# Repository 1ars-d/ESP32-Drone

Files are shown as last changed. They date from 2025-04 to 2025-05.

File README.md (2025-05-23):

# ESP32 Custom Drone

## 🚁 Overview

A compact, custom-built **5.5″ quadcopter drone** powered by an **ESP32 microcontroller**. This project includes both hardware design (3D-printed components, PCB layout) and firmware (Arduino-based) for flight control.

Drone with battery

---

## 🔧 Firmware

The flight control software is written in **C++** using the **Arduino framework**. It runs a **250Hz control loop** to maintain drone stability using the following key features:

- **Sensor Fusion**: A **Kalman Filter** fuses gyroscope and accelerometer data to estimate orientation.
- **Control System**: Stabilization is achieved using a **cascaded PID control loop**.
- **Remote Input**: Directional control is handled via a **radio receiver**.
- **Live PID Tuning**: The drone can host a **local Wi-Fi web interface** for real-time PID tuning.
  > _The web-based tuning interface was adapted from [pratikPhadte/ESP32-Flight-controller-](https://github.com/pratikPhadte/ESP32-Flight-controller-)._

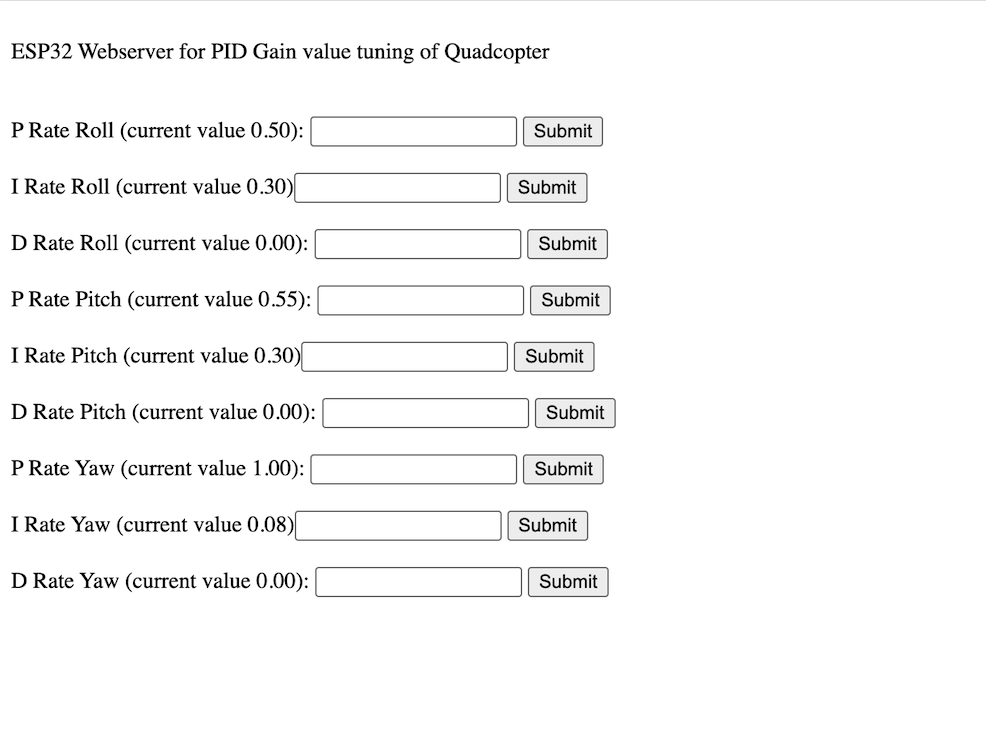
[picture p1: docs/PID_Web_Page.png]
PID Web Page


---

## 🛠️ Hardware Components

| Component | Description | Price |
| --- | --- | --- |
| **Frame** | FlyFishRC FIFTY5 | €50.00  |
| **Radio Receiver** | Flysky FS-IA6B | €20.00  |
| **Flight Controller** | ESP32-DevKitC, MP1584 (Buck Converter), MPU6050 (IMU), PCB | €20.00  |
| **Motors** | 4x FlyfishRC Flash 2306 1750Kv | €60.00  |
| **ESC** | 30.5mm 4-in-1 40A BLHeli32 | €50.00  |
| **Battery** | 3S 1500mAh LiPo | €20.00  |
| **Propellers** | 4x 5.5″ Props | €2.50 |
| **3D Printed Parts**  | Material cost for FC Case, RC Case, Feet | €2.00 |
| **Total** | | €224,50 |

> Note: The listed prices are approximate and may vary depending on the retailer or manufacturer. In this build, we intentionally used some higher-quality (and more expensive) components to ensure that budget parts wouldn't become a limiting factor in performance. However, with careful sourcing and smart purchasing decisions, the overall cost of this drone can be significantly reduced.

---

## 🧠 Flight Controller

The flight controller (FC) is based on an **ESP32 DevKitC**, mounted on a custom PCB. It integrates:

- **MPU6050 IMU** for motion sensing
- **MP1584 buck converter** to step down 10V (from ESC) to 5V

Connections are made via **JST SH cables** to the ESC and radio receiver.

> ‼️ The VCC wire of the JST SH connector for the radio receiver is connected to the ESP32’s 3.3V output. However, the receiver used in this project (FS-IA6B) requires a minimum operating voltage of 4.0V. To address this, an additional VCC wire was manually soldered to the ESP32’s 5V pin to provide sufficient power. While some 5V receivers may appear to function at 3.3V in test setups, our testing showed that the receiver's output becomes unstable when the motors are running, likely due to temporary voltage drops. For reliable performance, ensure the receiver is properly powered with a stable 5V supply.

Drone with open FC case

---

## 🧾 PCB Design

Designed using **KiCad** and manufactured by **JLCPCB**.

### 🔌 Schematic

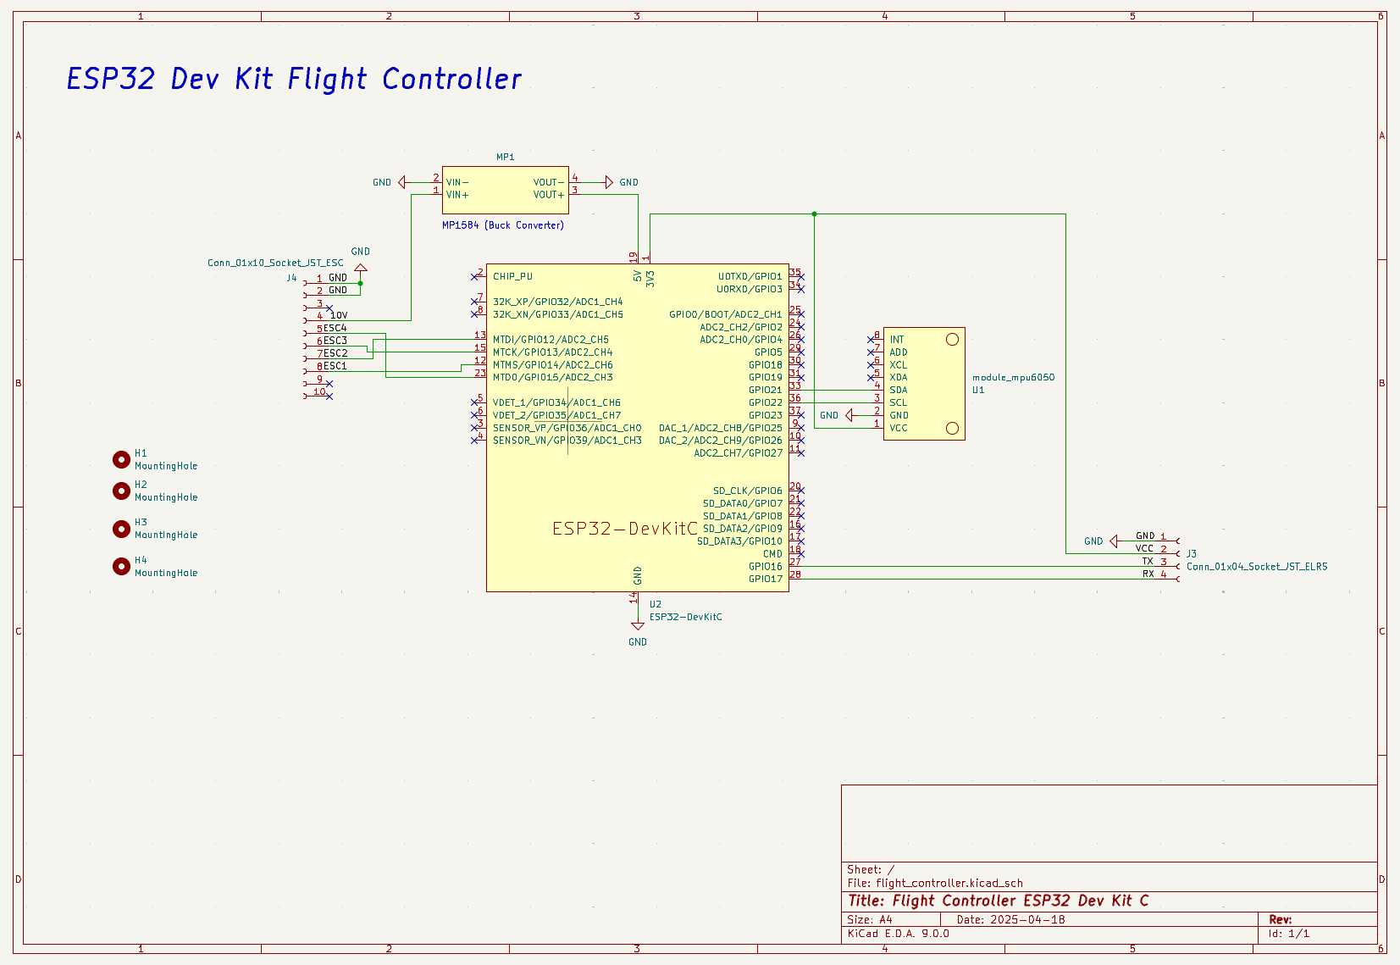
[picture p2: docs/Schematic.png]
Schematic


### 🔄 Routing

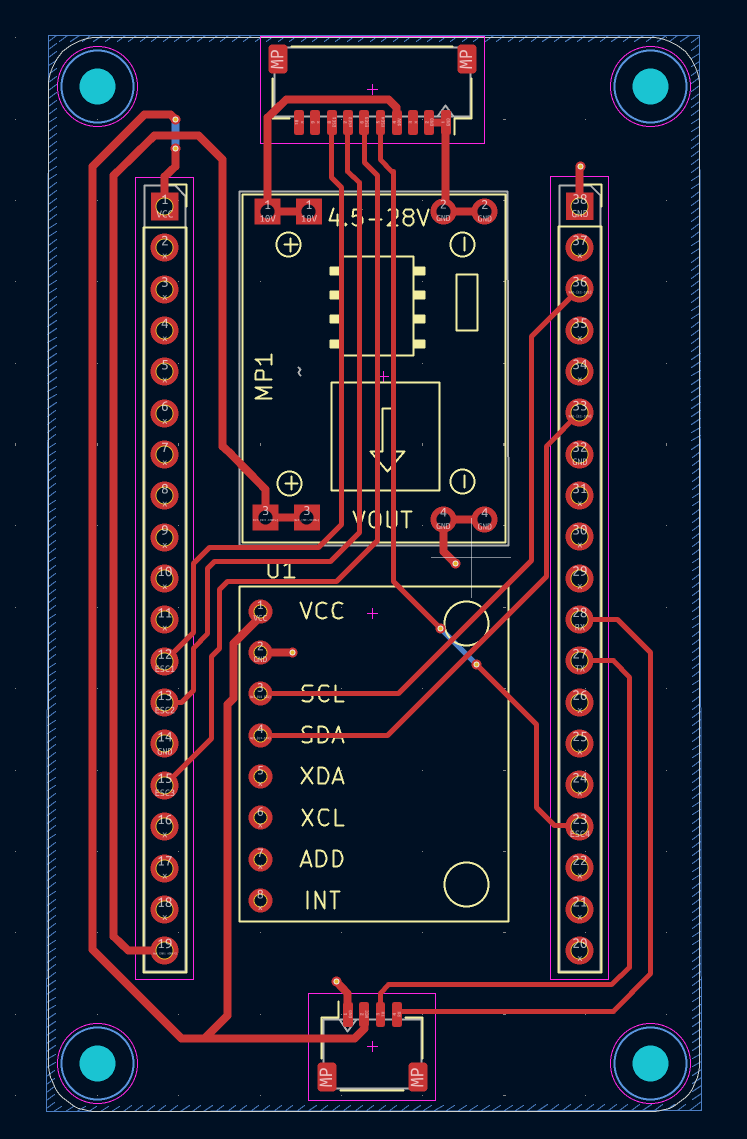
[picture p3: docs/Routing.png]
Routing


### 3D Model

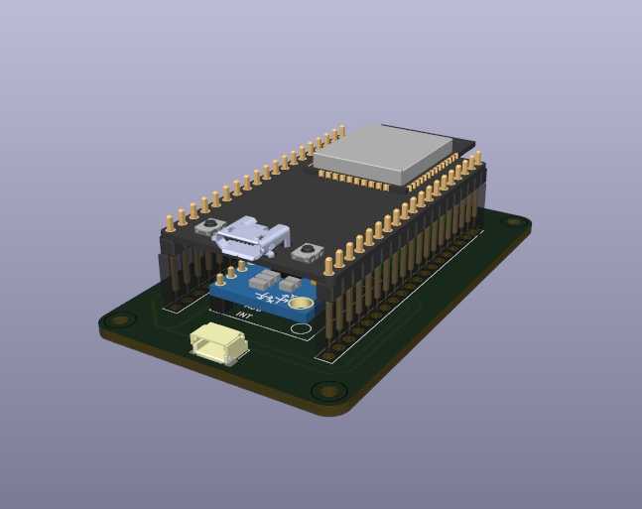
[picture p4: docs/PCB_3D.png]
PCB 3D


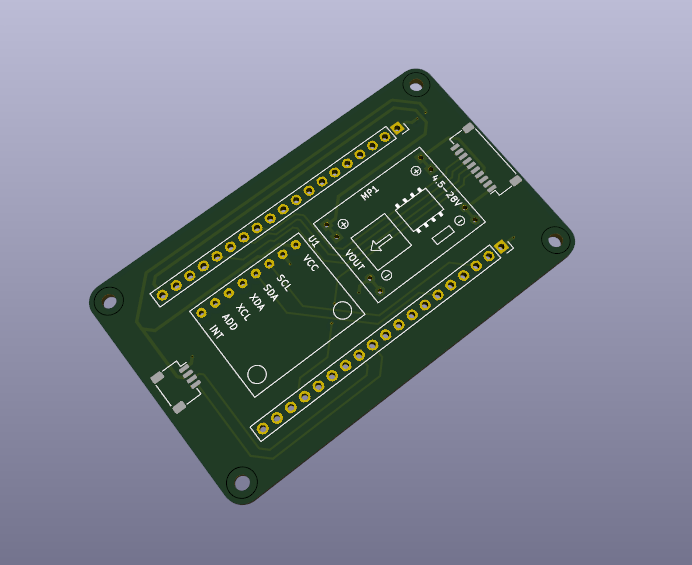
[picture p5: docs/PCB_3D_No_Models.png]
PCB 3D no models


---

## 🖨️ 3D Printed Parts

All parts were designed in **Autodesk Fusion 360** and printed using **PLA**. **M2/M3 threaded heat inserts** are used to mount components to the carbon frame.

All 3D Prints

### 📦 Flight Controller Case

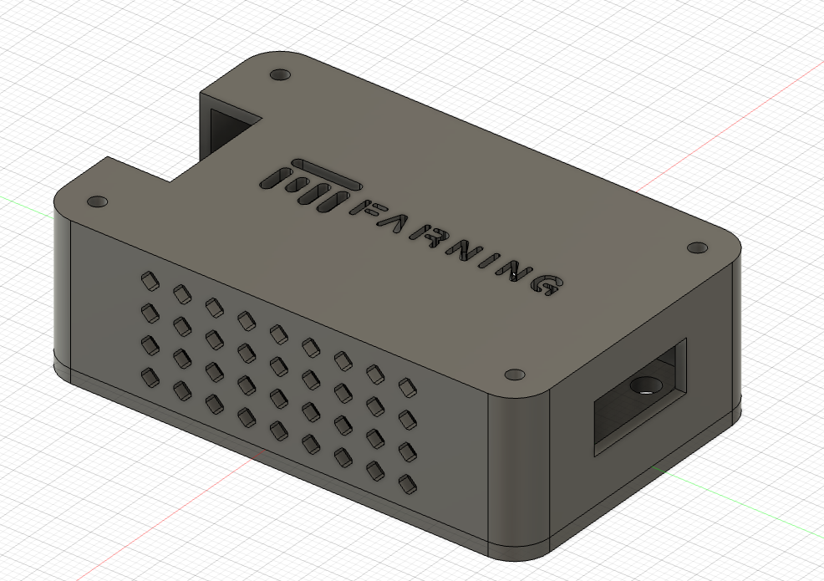
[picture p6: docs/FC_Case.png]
FC Case

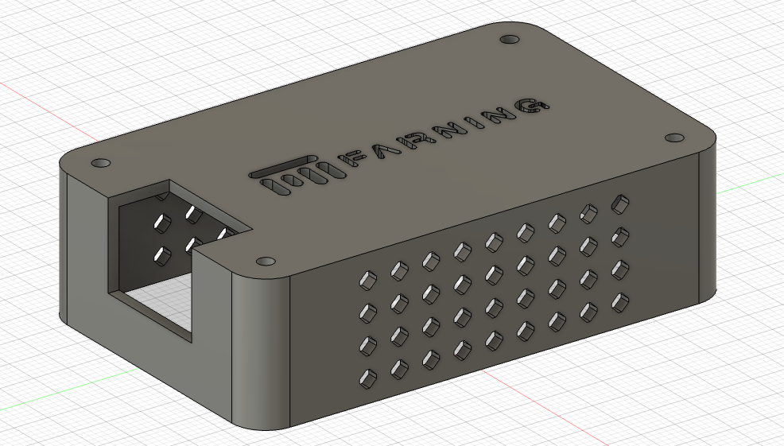
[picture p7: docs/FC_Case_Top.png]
FC Top

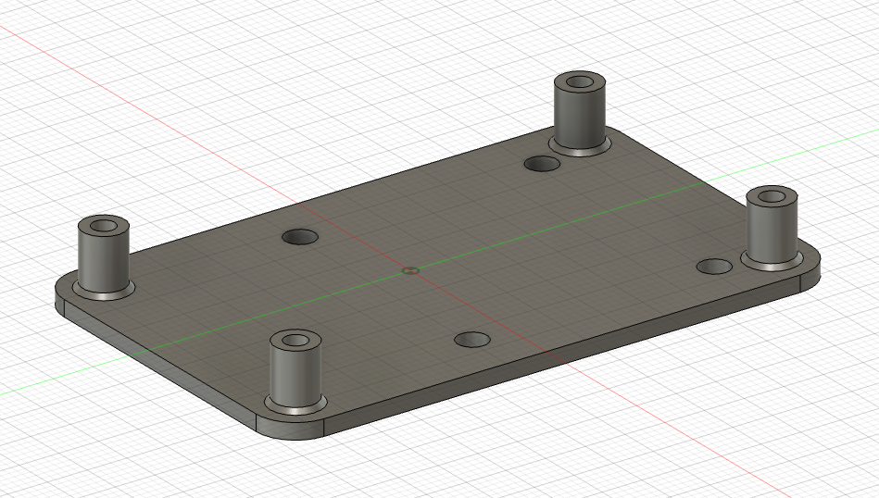
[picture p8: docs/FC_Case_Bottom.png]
FC Bottom

FC Bottom Screws
ESC

### 📡 Radio Receiver Case

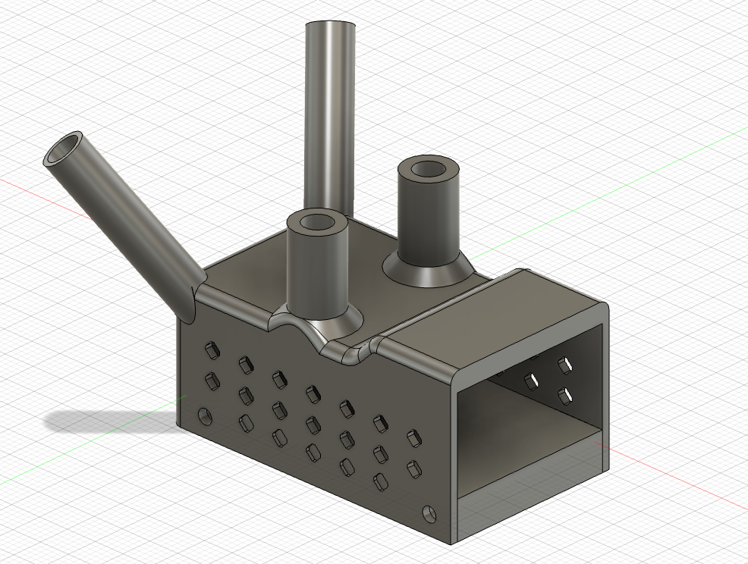
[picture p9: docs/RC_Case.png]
RC Case


RC Case Open

### 🧩 Miscellaneous Parts

**Spacers**  
Spacers

**Feet**  
Model from [Cults3D – FlyFishRC Volador Arm Protection](https://cults3d.com/de/modell-3d/spiel/flyfishrc-volador-5-6-full-arm-protection)  
Foot

---

## 👥 Contributors

- Tilman Kurmayer (https://github.com/tchello45)
- Melina Leitermann (https://github.com/me1ina1)

## 📚 References & Inspirations

This project was inspired and guided by the following open-source resources:

- [CarbonAeronautics/Manual-Quadcopter-Drone](https://github.com/CarbonAeronautics/Manual-Quadcopter-Drone)
- [pratikPhadte/ESP32-Flight-controller-](https://github.com/pratikPhadte/ESP32-Flight-controller-)

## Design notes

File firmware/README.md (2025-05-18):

# ESP32 Flight Controller

This project uses an **ESP32** microcontroller programmed via the **Arduino IDE**. It includes support for servos, iBus communication, and a web interface using asynchronous networking.

## 🛠️ Requirements

Before getting started, make sure the following components are installed in your Arduino IDE.

### 1. ESP32 Board Package

- **Platform**: ESP32 by Espressif Systems
- **Version**: `2.0.16`
- Install this via **Tools > Board > Boards Manager** by searching for `esp32`.

### 2. Required Libraries

Install the following libraries via **Sketch > Include Library > Manage Libraries**:

| Library | Version | Author |
| --- | --- | --- |
| ESP32Servo | 3.0.6 | Kevin Harrington, John K. Bennett |
| IbusBM | 1.1.4 | larrydfc |
| AsyncTCP | 3.4.1 | ESP32Async |
| ESPAsyncWebServer | 3.1.0 | lacamera |

Use the version selector in the Library Manager to install the specified versions.

## ✅ Setup Instructions

1. Connect your ESP32 board to your computer via USB.
2. In Arduino IDE:
   - Select your board under **Tools > Board**.
   - Select the correct **Port** under **Tools > Port**.
3. Open the project `.ino` file.
4. Click **Upload** to flash the code to your ESP32.

## ℹ️ Notes

- Library versions are important for compatibility—be sure to match them exactly.
- If you're using an alternate development environment (like PlatformIO), set dependencies to the specified versions.

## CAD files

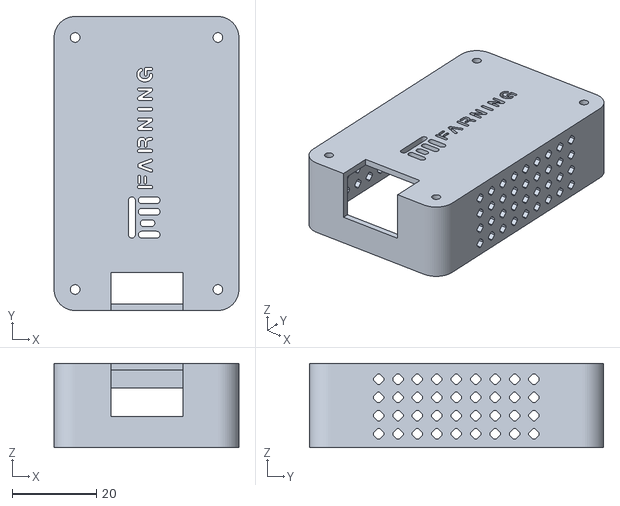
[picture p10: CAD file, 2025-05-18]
3d_print/ESP32 FC Case Top.stl
44.0 x 70.0 x 20.0

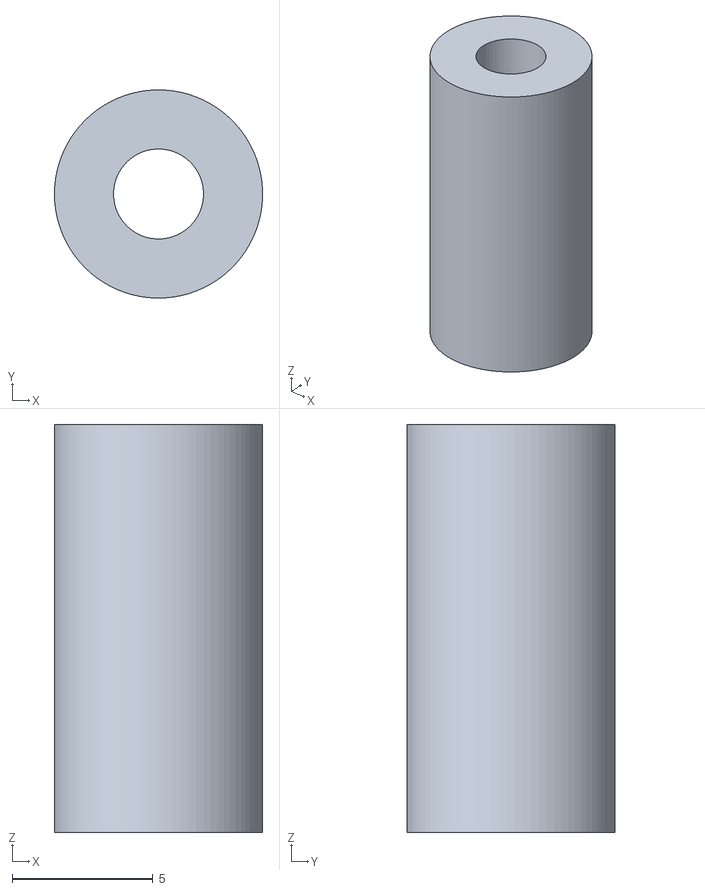
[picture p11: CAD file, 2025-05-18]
3d_print/Spacer.stl
7.40 x 7.40 x 14.5

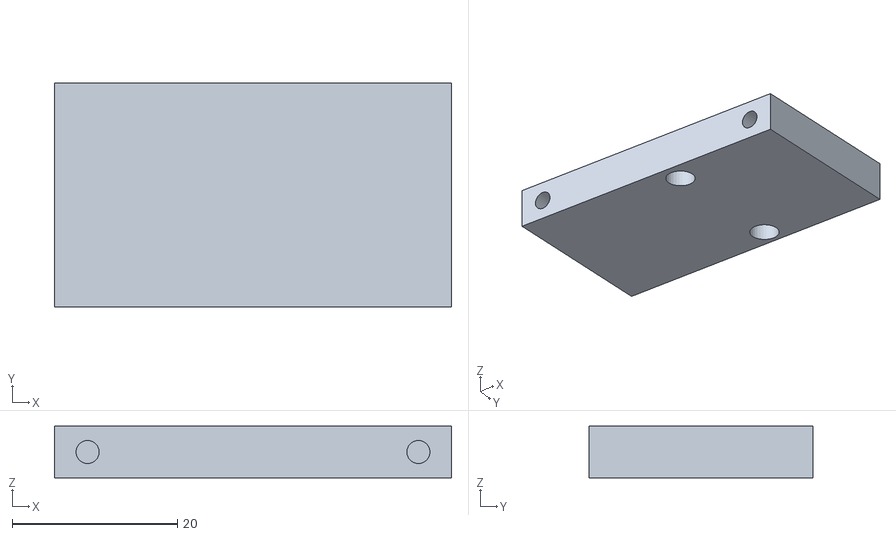
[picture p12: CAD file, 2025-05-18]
3d_print/FS Receiver Case Bottom.stl
48.0 x 27.1 x 6.26

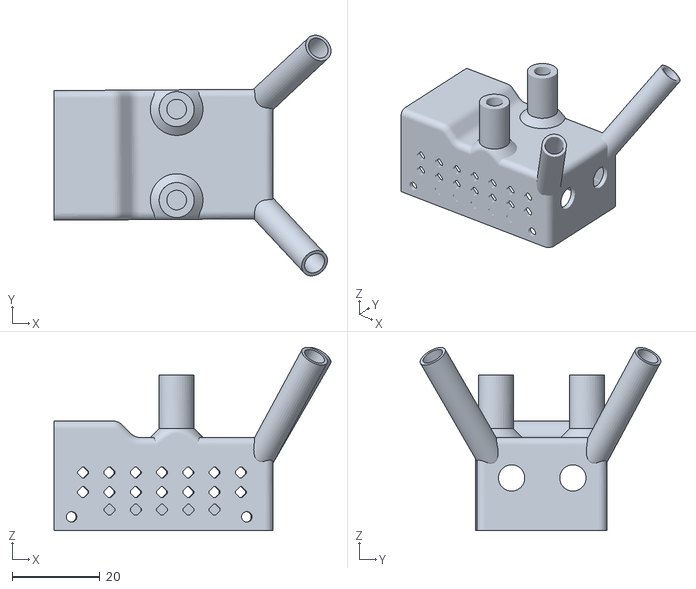
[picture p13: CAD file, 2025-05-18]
3d_print/FS Receiver Case Top.stl
63.2 x 55.0 x 41.8

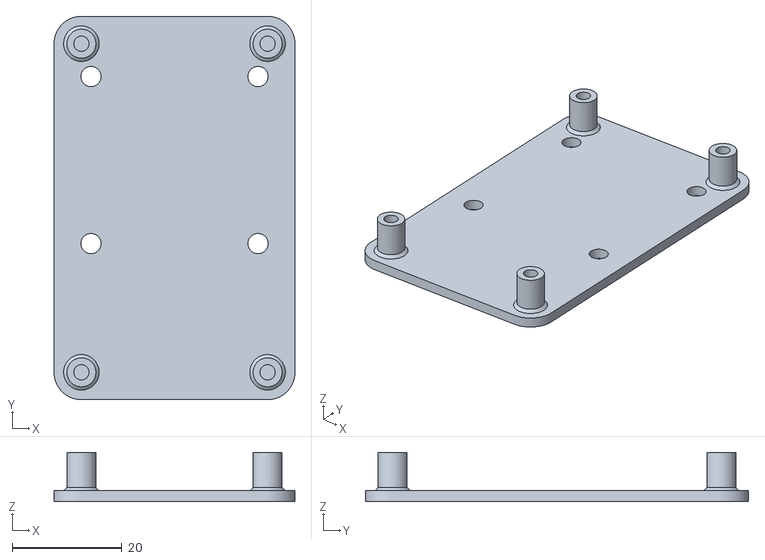
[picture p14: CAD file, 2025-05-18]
3d_print/ESP32 FC Case Bottom.stl
44.0 x 70.0 x 9.00

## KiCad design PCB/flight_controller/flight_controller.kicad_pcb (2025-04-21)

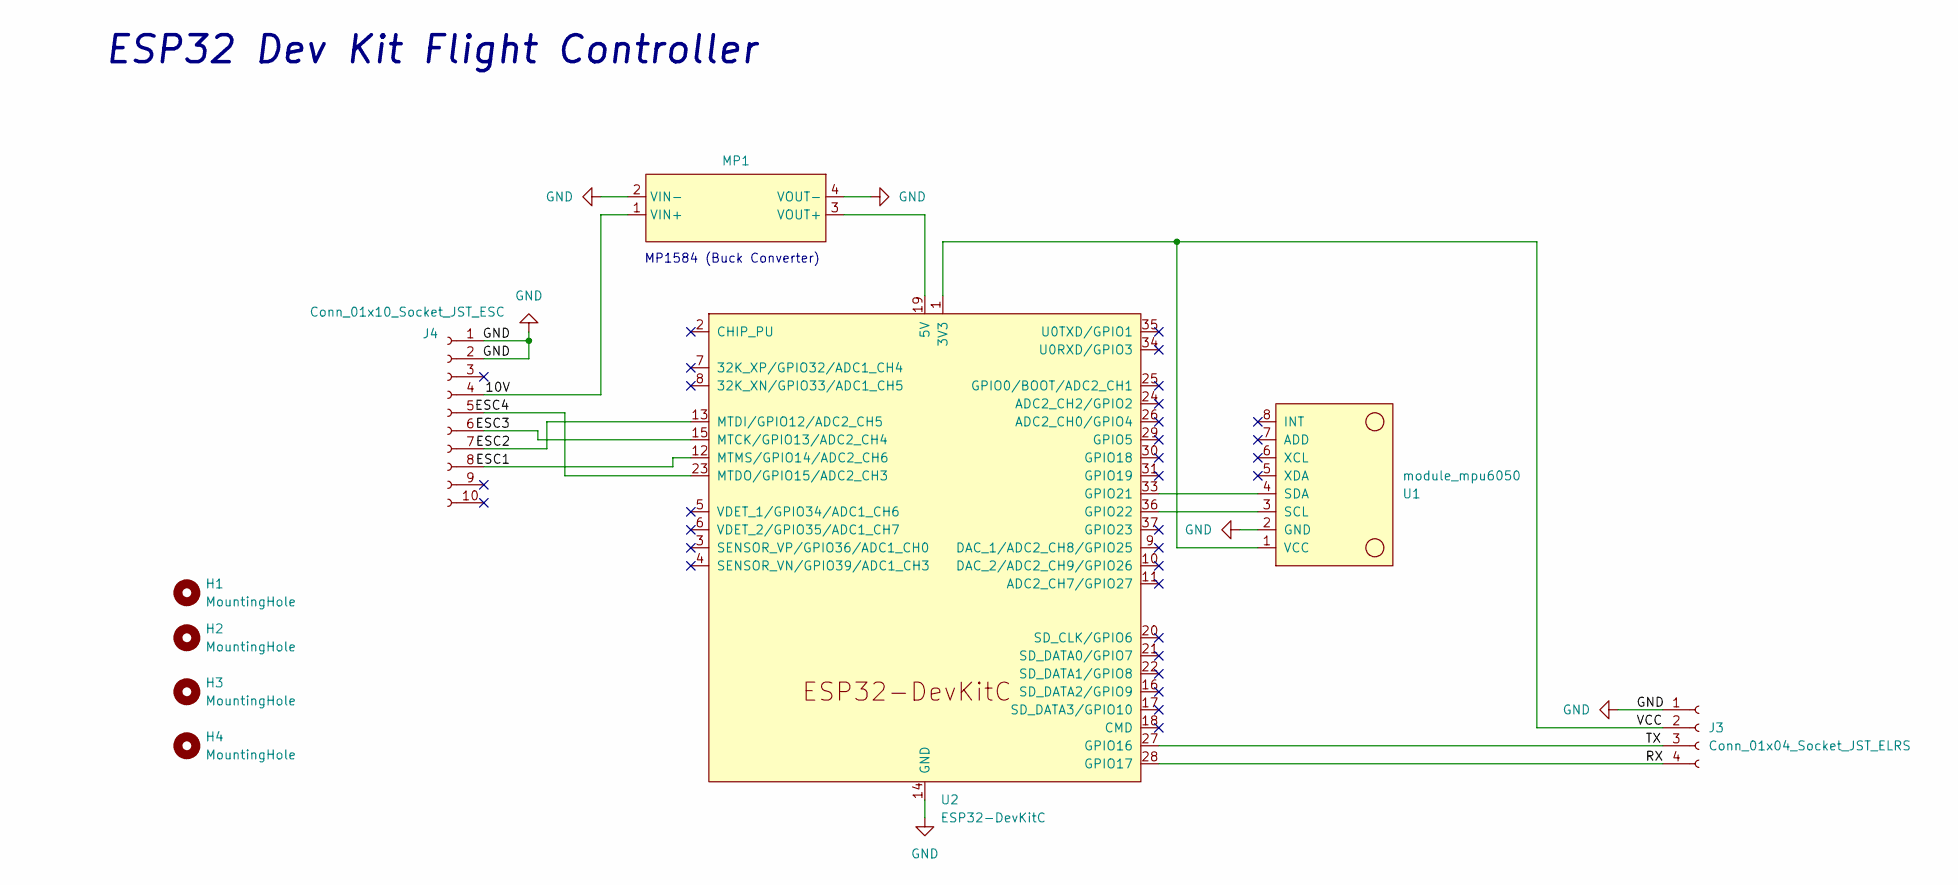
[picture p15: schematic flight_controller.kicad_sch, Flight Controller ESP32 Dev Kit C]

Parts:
H1, H2, H3, H4: MountingHole; MountingHole_2.2mm_M2
J3: Conn_01x04_Socket_JST_ELRS; JST_SH_SM04B-SRSS-TB_1x04-1MP_P1.00mm_Horizontal
J4: Conn_01x10_Socket_JST_ESC; JST_SH_SM10B-SRSS-TB_1x10-1MP_P1.00mm_Horizontal
MP1: SRT_MPT1584EN_Module
U1: module_mpu6050
U2: ESP32-DevKitC; ESP32 DevKitC Socket

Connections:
/10V: J4.4, MP1.1 (VIN+)
/ESC1: J4.8, U2.12 (MTMS/GPIO14/ADC2_CH6)
/ESC2: J4.7, U2.13 (MTDI/GPIO12/ADC2_CH5)
/ESC3: J4.6, U2.15 (MTCK/GPIO13/ADC2_CH4)
/ESC4: J4.5, U2.23 (MTDO/GPIO15/ADC2_CH3)
/RX: J3.4, U2.28 (GPIO17)
/TX: J3.3, U2.27 (GPIO16)
/VCC: J3.2, U1.1 (VCC), U2.1 (3V3)
GND: J3.1, J4.1, J4.2, MP1.2 (VIN-), MP1.4 (VOUT-), U1.2 (GND), U2.14 (GND), U2.32 (GND), U2.38 (GND)
unnamed: MP1.3 (VOUT+), U2.19 (5V)
unnamed: U1.3 (SCL), U2.36 (GPIO22)
unnamed: U1.4 (SDA), U2.33 (GPIO21)

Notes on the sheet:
MP1584 (Buck Converter)
ESP32 Dev Kit Flight Controller

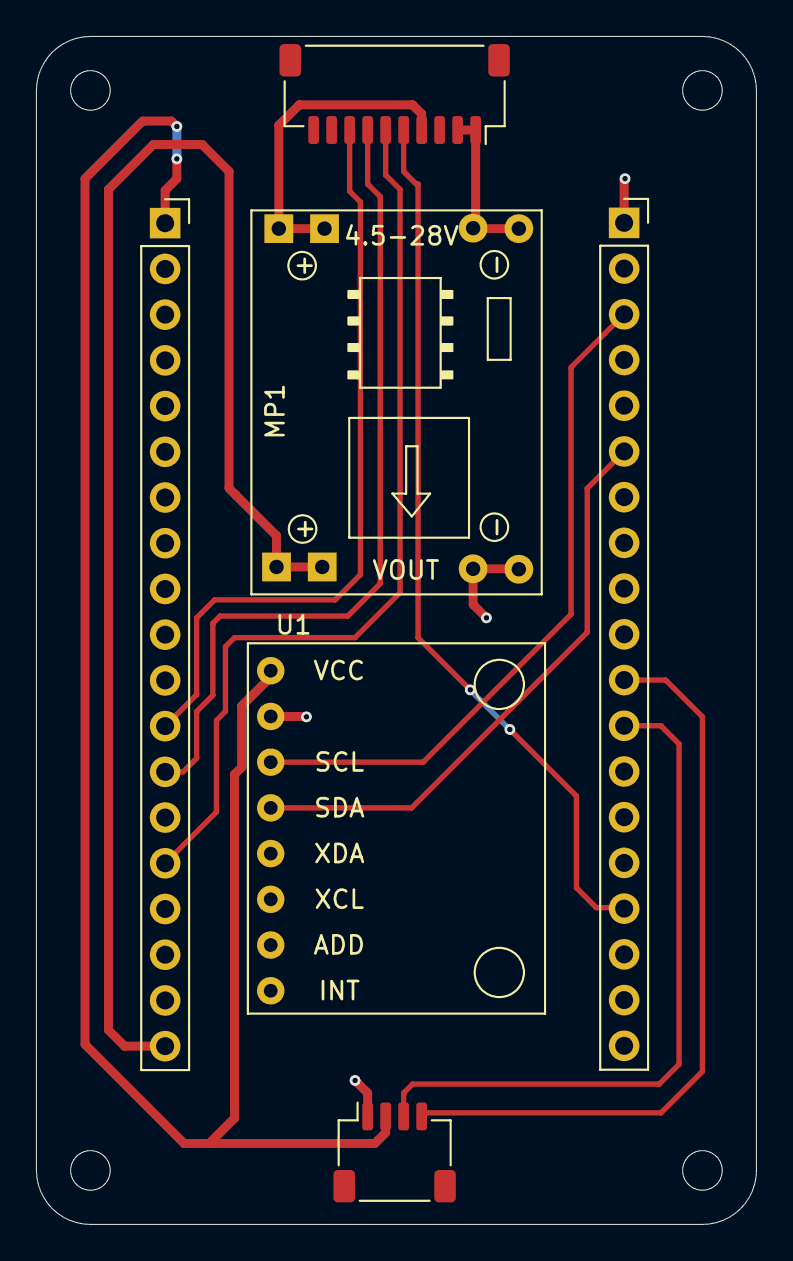
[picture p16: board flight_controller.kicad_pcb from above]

Board: 2 copper layers, 40.0 x 66.0 mm, 9 parts (0 on the bottom side), 12 nets.

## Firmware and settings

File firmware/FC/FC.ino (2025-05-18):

#include <IBusBM.h>
#include <ESP32Servo.h>
#include "KalmanAngles.h"
#include "WifiTuning.h"

// === CONFIG ===
#define REAR_RIGHT_ESC_PIN 14
#define FRONT_RIGHT_ESC_PIN 12
#define REAR_LEFT_ESC_PIN 13
#define FRONT_LEFT_ESC_PIN 15
#define IBUS_PIN 16

// === CONSTANTS ===
constexpr int LOOP_INTERVAL_US = 4000;
constexpr int MAX_MOTOR_OUTPUT = 2000;
constexpr int MIN_MOTOR_IDLE = 1180;
constexpr int MOTOR_CUTOFF = 1000;

// === STRUCTS ===
struct PIDParams
{
  float P, I, D;
};

struct PIDState
{
  float prevError = 0.0;
  float prevIterm = 0.0;
};

struct PIDController
{
  PIDParams params;
  PIDState state;
};

struct ControlSignals
{
  float roll = 0, pitch = 0, yaw = 0;
  float throttle = 0;
};

struct MotorOutputs
{
  float FR = 0, FL = 0, RR = 0, RL = 0;
};

// === GLOBALS ===
IBusBM ibus;
Servo escFR, escFL, escRR, escRL;

ControlSignals radioInput, desiredAngles, desiredRates;
ControlSignals measuredAngles, measuredRates;
ControlSignals pidOutputAngle, pidOutputRate;
MotorOutputs motorOutput;

unsigned long loopTimer = 0;

// Kalman IMU object
KalmanIMU imu;

// PID Controller Instances
PIDController pidAngleRoll{{2.0, 0.0, 0.0}};
PIDController pidAnglePitch{{2.0, 0.0, 0.0}};
PIDController pidRateRoll{{0.5, 0.3, 0.005}};
PIDController pidRatePitch{{0.55, 0.3, 0.005}};
PIDController pidRateYaw{{1.2, 0.2, 0.005}};

// === FUNCTION DECLARATIONS ===
float computePID(PIDController &controller, float error, float dt)
{
  float Pterm = controller.params.P * error;
  float Iterm = controller.state.prevIterm + controller.params.I * (error + controller.state.prevError) * dt / 2.0;
  float Dterm = controller.params.D * (error - controller.state.prevError) / dt;

  Iterm = constrain(Iterm, -400, 400);
  float output = constrain(Pterm + Iterm + Dterm, -400, 400);

  controller.state.prevError = error;
  controller.state.prevIterm = Iterm;

  return output;
}

void resetAllPID()
{
  for (PIDController *pid : {&pidAngleRoll, &pidAnglePitch, &pidRateRoll, &pidRatePitch, &pidRateYaw})
  {
    pid->state.prevError = 0;
    pid->state.prevIterm = 0;
  }
}

// === SETUP ===
void setup()
{
  Serial.begin(115200);
  delay(1500);

  escFR.attach(FRONT_RIGHT_ESC_PIN);
  escFL.attach(FRONT_LEFT_ESC_PIN);
  escRR.attach(REAR_RIGHT_ESC_PIN);
  escRL.attach(REAR_LEFT_ESC_PIN);

  Serial.println("Arming motors...");
  for (Servo *esc : {&escFR, &escFL, &escRR, &escRL})
    esc->writeMicroseconds(1000);

  Serial.println("Starting gyro calibration...");
  imu.setup(); // neue KalmanIMU-Kalibrierung

  //setup__wifi_tuning();

  Serial.println("Connecting IBUS...");
  ibus.begin(Serial2, 1, IBUS_PIN, -1);

  loopTimer = micros();
}

// === LOOP ===
void loop()
{
  static unsigned long lastLog = 0;
  unsigned long now = micros();
  float dt = (now - loopTimer) / 1e6;
  if (dt >= LOOP_INTERVAL_US / 1e6) {
    loopTimer = micros();
    // === RADIO INPUT ===
    radioInput.roll = ibus.readChannel(0);
    radioInput.pitch = ibus.readChannel(1);
    radioInput.throttle = ibus.readChannel(2);
    radioInput.yaw = ibus.readChannel(3);

    // Apply deadband for roll and pitch
    if (abs(radioInput.roll - 1500) < 11)
      radioInput.roll = 1500;
    if (abs(radioInput.pitch - 1500) < 11)
      radioInput.pitch = 1500;

    // === MAP RC INPUT TO DESIRED ANGLES / RATES ===
    desiredAngles.roll = 0.10 * (radioInput.roll - 1500);
    desiredAngles.pitch = -0.10 * (radioInput.pitch - 1500);
    desiredRates.yaw = -0.15 * (radioInput.yaw - 1500);

    // === SENSOR UPDATE ===
    imu.update();
    measuredAngles.roll = imu.getKalmanRoll(dt);
    measuredAngles.pitch = imu.getKalmanPitch(dt);
    measuredRates.roll = imu.getDroneRateRoll();
    measuredRates.pitch = imu.getDroneRatePitch();
    measuredRates.yaw = imu.getRateYaw();

    // === OUTER PID LOOP (ANGLE → RATE) ===
    float angleErrorRoll = desiredAngles.roll - measuredAngles.roll;
    float angleErrorPitch = desiredAngles.pitch - measuredAngles.pitch;
    desiredRates.roll = computePID(pidAngleRoll, angleErrorRoll, dt);
    desiredRates.pitch = computePID(pidAnglePitch, angleErrorPitch, dt);

    // === LOAD TUNED RATE PID PARAMETERS (via WiFi) ===
    pidRateRoll.params = {WifiPRateRoll, WifiIRateRoll, WifiDRateRoll};
    pidRatePitch.params = {WifiPRatePitch, WifiIRatePitch, WifiDRatePitch};
    pidRateYaw.params = {WifiPRateYaw, WifiIRateYaw, WifiDRateYaw};

    // === INNER PID LOOP (RATE → ACTUATION) ===
    float rateErrorRoll = desiredRates.roll - measuredRates.roll;
    float rateErrorPitch = desiredRates.pitch - measuredRates.pitch;
    float rateErrorYaw = desiredRates.yaw - measuredRates.yaw;

    pidOutputRate.roll = computePID(pidRateRoll, rateErrorRoll, dt);
    pidOutputRate.pitch = computePID(pidRatePitch, rateErrorPitch, dt);
    pidOutputRate.yaw = computePID(pidRateYaw, rateErrorYaw, dt);

    // === MIX PID OUTPUTS INTO MOTOR SIGNALS ===
    float t = constrain(radioInput.throttle, 1000, 1800);

    // Safety condition: below minimum throttle → stop motors & reset PID
    if (t < 1050)
    {
      resetAllPID();
      motorOutput.FR = MOTOR_CUTOFF;
      motorOutput.RR = MOTOR_CUTOFF;
      motorOutput.FL = MOTOR_CUTOFF;
      motorOutput.RL = MOTOR_CUTOFF;
    }
    else
    {
      motorOutput.FR = t - pidOutputRate.roll + pidOutputRate.pitch + pidOutputRate.yaw;
      motorOutput.RR = t - pidOutputRate.roll - pidOutputRate.pitch - pidOutputRate.yaw;
      motorOutput.FL = t + pidOutputRate.roll + pidOutputRate.pitch - pidOutputRate.yaw;
      motorOutput.RL = t + pidOutputRate.roll - pidOutputRate.pitch + pidOutputRate.yaw;

      for (float *motor : {&motorOutput.FR, &motorOutput.FL, &motorOutput.RR, &motorOutput.RL})
      {
        *motor = constrain(*motor, MIN_MOTOR_IDLE, MAX_MOTOR_OUTPUT - 1);
      }
    }

    // === ESC OUTPUT ===
    escFR.writeMicroseconds(motorOutput.FR);
    escFL.writeMicroseconds(motorOutput.FL);
    escRR.writeMicroseconds(motorOutput.RR);
    escRL.writeMicroseconds(motorOutput.RL);

    // === OPTIONAL DEBUG: LOG LOOP FREQUENCY ===
    if (millis() - lastLog > 1000)
    {
      Serial.print("Loop frequency: ");
      Serial.println(1.0 / dt);
      lastLog = millis();
    }

  }

  delay(1);
}

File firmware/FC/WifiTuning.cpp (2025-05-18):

#include <WiFi.h>
#include <AsyncTCP.h>
#include <ESPAsyncWebServer.h>
#include "WifiTuning.h"

const char *ssid = "";
const char *password = "";

AsyncWebServer server(80);

const char *PARAM_P_RATE_ROLL = "pRateRoll";
const char *PARAM_I_RATE_ROLL = "iRateRoll";
const char *PARAM_D_RATE_ROLL = "dRateRoll";

const char *PARAM_P_RATE_PITCH = "pRatePitch";
const char *PARAM_I_RATE_PITCH = "iRatePitch";
const char *PARAM_D_RATE_PITCH = "dRatePitch";

const char *PARAM_P_RATE_YAW = "pRateYaw";
const char *PARAM_I_RATE_YAW = "iRateYaw";
const char *PARAM_D_RATE_YAW = "dRateYaw";

float WifiPRateRoll = 0.5;
float WifiIRateRoll = 0.30;
float WifiDRateRoll = 0.005;

float WifiPRatePitch = 0.55;
float WifiIRatePitch = 0.30;
float WifiDRatePitch = 0.005;

float WifiPRateYaw = 1.0;
float WifiIRateYaw = 0.1;
float WifiDRateYaw = 0.005;

float WifiPAngle;
float WifiIAngle;
float WifiDAngle;

// HTML web page to handle 6 input fields of PID gains
const char index_html[] PROGMEM = R"rawliteral(
<!DOCTYPE HTML><html><head>
  <title>ESP Input Form</title>
  <meta name="viewport" content="width=device-width, initial-scale=1">
  <script>
    function submitMessage() {
      alert("Saved value to ESP SPIFFS");
      setTimeout(function(){ document.location.reload(false); }, 500);
    }
  </script></head>

  <body>

     <form action="/get" target="hidden-form"><br>
    ESP32 Webserver for PID Gain value tuning of Quadcopter 
  </form><br><br>

  <form action="/get" target="hidden-form">
    P Rate Roll (current value %pRateRoll%): <input type="number" step="any" name="pRateRoll">
    <input type="submit" value="Submit" onclick="submitMessage()">
  </form><br>
  <form action="/get" target="hidden-form">
    I Rate Roll (current value %iRateRoll%)<input type="number" step="any" name="iRateRoll">
    <input type="submit" value="Submit" onclick="submitMessage()">
  </form><br>
  <form action="/get" target="hidden-form">
    D Rate Roll (current value %dRateRoll%): <input type="number" step="any" name="dRateRoll">
    <input type="submit" value="Submit" onclick="submitMessage()">
  </form><br>

  <form action="/get" target="hidden-form">
    P Rate Pitch (current value %pRatePitch%): <input type="number" step="any" name="pRatePitch">
    <input type="submit" value="Submit" onclick="submitMessage()">
  </form><br>
  <form action="/get" target="hidden-form">
    I Rate Pitch (current value %iRatePitch%)<input type="number" step="any" name="iRatePitch">
    <input type="submit" value="Submit" onclick="submitMessage()">
  </form><br>
  <form action="/get" target="hidden-form">
    D Rate Pitch (current value %dRatePitch%): <input type="number" step="any" name="dRatePitch">
    <input type="submit" value="Submit" onclick="submitMessage()">
  </form><br>

  <form action="/get" target="hidden-form">
    P Rate Yaw (current value %pRateYaw%): <input type="number" step="any" name="pRateYaw">
    <input type="submit" value="Submit" onclick="submitMessage()">
  </form><br>
  <form action="/get" target="hidden-form">
    I Rate Yaw (current value %iRateYaw%)<input type="number" step="any" name="iRateYaw">
    <input type="submit" value="Submit" onclick="submitMessage()">
  </form><br>
  <form action="/get" target="hidden-form">
    D Rate Yaw (current value %dRateYaw%): <input type="number" step="any" name="dRateYaw">
    <input type="submit" value="Submit" onclick="submitMessage()">
  </form><br>

  <iframe style="display:none" name="hidden-form"></iframe>
</body></html>)rawliteral";

void notFound(AsyncWebServerRequest *request)
{
  request->send(404, "text/plain", "Not found");
}

String processor(const String &var)
{
  if (var == "pRateRoll")
  {
    return String(WifiPRateRoll);
  }

  if (var == "iRateRoll")
  {
    return String(WifiIRateRoll);
  }

  if (var == "dRateRoll")
  {
    return String(WifiDRateRoll);
  }

  if (var == "pRatePitch")
  {
    return String(WifiPRatePitch);
  }

  if (var == "iRatePitch")
  {
    return String(WifiIRatePitch);
  }

  if (var == "dRatePitch")
  {
    return String(WifiDRatePitch);
  }

  if (var == "pRateYaw")
  {
    return String(WifiPRateYaw);
  }

  if (var == "iRateYaw")
  {
    return String(WifiIRateYaw);
  }

  if (var == "dRateYaw")
  {
    return String(WifiDRateYaw);
  }

  return "";
}

void setup__wifi_tuning()
{
  WiFi.mode(WIFI_STA);
  WiFi.begin(ssid, password);
  Serial.print("Connecting to WiFi");
  int retryCount = 0;
  while (WiFi.status() != WL_CONNECTED && retryCount < 20)
  {
    delay(500);
    Serial.print(".");
    retryCount++;
  }

  if (WiFi.status() == WL_CONNECTED)
  {
    Serial.println("\n✅ WiFi connected.");
    Serial.print("IP Address: ");
    Serial.println(WiFi.localIP());
  }
  else
  {
    Serial.println("\n❌ WiFi failed after 10 seconds.");
  }
  Serial.println();
  Serial.print("IP Address: ");

  Serial.println(WiFi.localIP());
  delay(2000);
  // Send web page with input fields to client
  server.on("/", HTTP_GET, [](AsyncWebServerRequest *request)
            { request->send_P(200, "text/html", index_html, processor); });
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

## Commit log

2025-04-18 pcb create symbols and footprints
    [flight_controller.kicad_pcb, flight_controller.kicad_sch]
2025-05-18 PCB updates
